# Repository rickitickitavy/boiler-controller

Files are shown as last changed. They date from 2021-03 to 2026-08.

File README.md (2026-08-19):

# Wood boiler controller

ESP32-WROOM firmware (PlatformIO / Arduino) for a wood boiler with three servo dampers (blowing, afterburning/oxygen, smoke), DS18x20 temperature sensing (boiler + thermal accumulator + house loops), and accumulated energy estimation.

## Build / flash

```bash
pio run
pio run -t upload
pio run -t uploadfs    # after changes under data/
pio device monitor     # 921600 (see platformio.ini)
```

Board: `esp32dev`. Upload port defaults to `/dev/ttyUSB0` in [`platformio.ini`](platformio.ini).

## Docs for agents / contributors

| File | Purpose |
|---|---|
| [`AGENTS.md`](AGENTS.md) | Agent entrypoint, constraints, key sources |
| [`docs/HANDOFF.md`](docs/HANDOFF.md) | Domain glossary, pins, FSM, energy math, known gaps |
| [`.cursor/skills/esp32/`](.cursor/skills/esp32/) | Project stack conventions |

## Stack snapshot

- ILI9488 TFT + XPT2046 touch
- DS18x20 on dual OneWire buses
- LEDC PWM servos for three doors
- LittleFS web UI under [`data/`](data/)
- EEPROM versioned settings (`GlobalSettings`)
- `ESPAsyncWebServer` + `AsyncTCP` via PlatformIO `lib_deps`

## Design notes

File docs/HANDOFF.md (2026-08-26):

# Wood boiler controller — handoff / context

PlatformIO project for **ESP32-WROOM** (`board = esp32dev`, `espressif32` / Arduino).  
Path: `/home/dsporynkhin/Projects/cpp/home/boilercontroller`

Use this file when starting a new chat (`@docs/HANDOFF.md`). Documented behavior is **as implemented today**.

## Domain glossary

| Domain | Code symbols |
|---|---|
| Blowing / bottom air door | `upper_door_*`, `UPPER_SERVO_PIN` |
| Afterburning / oxygen door | `oxygen_door_*`, `OXYGEN_SERVO_PIN` |
| Smoke / chimney door | `smoke_pipe_*`, `SMOKE_SERVO_PIN` |
| Fuel-loading hatch sensor | `MAIN_DOOR_SENSOR_PIN`, `main_door_opened` |
| Boiler core / out / in | `T_SENS_INDEX_CORE` / `OUTPUT_FLOW` / `INPUT_FLOW` |
| Thermal accumulator | top, middle_hi, middle_low, bottom |
| House heating supply / return | forward / backward flow |
| Stored energy | `accumulated_energy_kwt_hour` |
| Instant / smoothed core power | `current_core_power`, `core_EMA_power`, `core_DEMA_power` |
| Power balance | `power_balance_kwt_hour` (rate of change of stored energy) |

Primary goal: drive the three damper servos to burn safely (avoid overheating) and estimate accumulated thermal energy.

## Hardware (current)

Pins from [`include/pins.h`](../include/pins.h):

| Function | Macro | GPIO |
|---|---|---|
| Smoke servo | `SMOKE_SERVO_PIN` | 25 |
| Oxygen servo | `OXYGEN_SERVO_PIN` | 26 |
| Upper (blowing) servo | `UPPER_SERVO_PIN` | 27 |
| Emergency valve | `EMERGENCY_VALVE_PIN` | 0 |
| Pump 1–4 | `PUMP_1_PIN`…`PUMP_4_PIN` | 4, 13, 33, 32 |
| OneWire bus 1 / 2 | `ONE_WIRE_PIN`, `ONE_WIRE_PIN_2` | 14, **32** |
| Flow sensor | `FLOW_SENSOR_PIN` | 39 |
| TFT CS / DC / RST | `DISPLAY_*` | 17 / 15 / 16 |
| Touch CS / PENIRQ | `TOUCH_CS`, `TOUCH_PEN` | 12 / 36 |
| Fuel hatch sensor | `MAIN_DOOR_SENSOR_PIN` | 34 |
| External WDT kick | `EXTERNAL_WDT_PIN` | 5 |

- **MCU:** ESP32-WROOM (`esp32dev`)
- **Display:** custom local `lib/ILI9488` + XPT2046 touch (`TouchDisplayController`), rotation 1; Adafruit GFX / BusIO via `lib_deps`
- **Temps:** DS18x20 on two OneWire buses (`SensorController` + OneWire / DallasTemperature `lib_deps`); addresses in `GlobalSettings.ds18D20Addresses[]`
- **Doors:** three LEDC PWM servos (`Servo` / `ServoController` / `DoorsController`); all inverted; ~60 °/s rate limit
- **Pumps:** pumps 1–2 constructed in control path; 3–4 macros exist but are unused
- **FS:** **LittleFS** for web/`data/` assets (`board_build.filesystem = littlefs`)
- **Flash partitions:** stock PlatformIO **`default.csv`** — app0/app1 **1280 KB** each, LittleFS (`spiffs` subtype) **~1408 KB**, coredump **64 KB** (`board_build.partitions = default.csv`). First cutover after changing partitions needs a full erase + reflash (`upload` + `uploadfs`), not app-only OTA.
- **Web UI:** vanilla JS in `data/index.html` (Status / Settings / System shell; sidebar version `3.0.1`; Status card online time from telemetry `date_time_ms`; System inner tabs Log / Maintenance / Update) plus `data/js/*.js` — **no jQuery**. `data/settings.html` redirects to `/#settings`. TFT BMP icons remain under `data/img/`.
- **Settings:** EEPROM 4096 bytes, marker `0x34 0x32 0x33 0x31`, `GLOBAL_CURRENT_SETTINGS_VERSION` = 2

**Pin clash:** `ONE_WIRE_PIN_2` and `PUMP_4_PIN` both use GPIO **32**.

## Temperature sensors

| Index | `#define` | Settings path (approx.) | Meaning |
|---:|---|---|---|
| 0 | `T_SENS_INDEX_CORE` | `sensors>heater>core` | Boiler core |
| 1 | `T_SENS_INDEX_OUTPUT_FLOW` | `sensors>heater>output_flow` | Boiler output |
| 2 | `T_SENS_INDEX_INPUT_FLOW` | `sensors>heater>input_flow` | Boiler return/input |
| 3 | `T_SENS_INDEX_ACC_TOP` | `sensors>termoaccumulator>top` | Acc top |
| 4 | `T_SENS_INDEX_ACC_MID_HI` | `…>middle_hi` | Acc above middle |
| 5 | `T_SENS_INDEX_ACC_MID_LO` | `…>middle_low` | Acc below middle |
| 6 | `T_SENS_INDEX_ACC_BOTTOM` | `…>bottom` | Acc bottom |
| 7 | `T_SENS_INDEX_FORWARD_FLOW` | `sensors>forward>temperature` | House supply (“Warm T”) |
| 8 | `T_SENS_INDEX_BACKWARD_FLOW` | `sensors>backward>temperature` | House return |
| 9 | `T_SENS_INDEX_INTERNAL` | `sensors>internal>temperature` | Board/internal |

## Door control

### Fuel hatch override (`DoorsController::applyStatus`)

When `door_opened`: smoke **100%**, oxygen **0%** (immediate), upper **100%**. Otherwise programmed percentages apply.

### Heater modes (`HeaterMode` in `HeaterController.h`)

```
STAND_BY → WARMING → PID → FINAL_COOLING → STAND_BY
                ↘ OVERHEATED ↔ CRITICAL
Hard failsafe: core SMA ≥ 100 °C → CRITICAL
```

Comment also mentions `ALARM (BANG)` — **not implemented**.

| Mode | Smoke | Oxygen | Upper (blowing) | Notes |
|---|---|---|---|---|
| `STAND_BY` | 33% | 0% | 0% | Init-fire can temporarily open O₂ |
| `WARMING` | warming smoke % | 100% | warming upper % (gated) | Pumps typically on |
| `PID` | burning smoke % | PID `%` | burning upper % (gated) | Oxygen from `PidRegulator` |
| `FINAL_COOLING` | 33% | 0% | 0% | |
| `OVERHEATED` | 100% | 0% | 100% | Cool aggressively |
| `CRITICAL` | 100% | 0% | 100% | + emergency valve HIGH |

**Defaults:** `core_overheat` 96 °C → OVERHEATED; `core_critical` 99 °C → CRITICAL.

**Init fire** (`openOxygenDoorForTime`, default `TIME_FOR_INIT_FIRE_SEC` = 900): O₂ 100%, smoke 66%; on close → O₂ 0%, smoke 33%. UI button + web `/openDoorFor15Min`.

**Upper-door safety** (`calculateUpperDoorValue`): if power acceleration ≤ 0 **and** `core_EMA_power < core_power_to_close_upper_door_if_ICPD_W`, force upper **0%**.

**Stub:** `handle_DOOR_OPENED_mode()` is empty TODO.

## Power and accumulated energy

Constants in `Defines.h`: `WATER_ENERGY_PER_LTR_PER_GRAD` = 4200, `JOUL_PER_KWTCH` = 3_600_000, `LOWEST_TEMPERATURE_FOR_ACCUMULATOR` = 35 °C.

**Core power** (`calcMainCoreCharacteristics`):

- Pumps off: ΔT_core × `heater_core_ltr` × 4200 / Δt
- Pumps on: (T_out − T_in) × flow × 4200 / Δt  
  Then EMA / DEMA smoothing into `core_EMA_power` / `core_DEMA_power`.

**Stored energy** (`collectTelemetry`):

```
avg_acc = mean(top, bottom, mid_lo, mid_hi) SMA
E_kWh = ((T_top − 35) × boiler_ltr + (avg_acc − 35) × accumulator_ltr)
        × 4200 / 3_600_000
```

→ `accumulated_energy_kwt_hour` (UI: “Energy kWh”).

**Power balance:** `Intervals(30)` tracks stored energy over time; code then reads `getInterval(39)` while capacity is 30 — **likely buggy**; treat balance values cautiously.

## TFT UI

- Active path: `screen_index == 0` — 3×3 gauge grid + pump / init-fire / Settings buttons (`TouchDisplayController`)
- `screen_index == 1` — Settings: left vertical tabs joined to page body (Info, WiFi, Mqtt, Sensors, Servo, Capasit., Rules, Modes); idle **20 s** returns to main (unsaved drafts discarded); heater/sensors keep running while open
- **Info** tab: WiFi MAC (`esp_read_mac` STA) + WiFi Status/RSSI + MQTT Connected/Disconnected (1 s per-line refresh)
- **WiFi / MQTT / Sensors / Servo / Capasit. / Rules / Modes** tabs: scrollable forms via `SettingsTftForms` + `src/lib/ui/form/*`; on-screen keyboard `src/lib/ui/keyboard/OnScreenKeyboard.*` (may overlay footer)
- Capasit. / Rules / Modes mirror matching Web UI sections; section blocks separated by non-interactive header labels
- Number / text field limits (min/max, string max len) come from `SettingsNavigator` `ParamDescriptor`s — same ranges as web settings
- Full-width footer (**26 px**): Reload / Cancel / Save — Cancel closes without save; Save writes EEPROM **without restart**; calls `WiFiController::reapplyNetworkSettings()` **only if WiFi SSID/password changed**; always calls `MqttController::reloadFromSettings()`
- Sensors: 10 address dropdowns (discovered OneWire + `0000000000000000`); Servo order Smoke → Oxygen → Upper
- Gauges include Core T, Core P, Warm T, Output T, Pwr P, Top T, Input T, Energy kWh, Bottom T
- Mid-acc sensors feed energy math but are not dedicated main gauges
- `drawScreen1` (door % layout) largely commented out
- BMP icons from LittleFS (`/img/…`)
- Web settings UI is a tabbed page in `data/index.html` (`/settingsApi`) alongside TFT forms

## Network / OTA / persistence

| Concern | As-is behavior |
|---|---|
| WiFi | STA to `network.ssid/password`; fail → AP `{mqttDeviceName}-WiFi` / `00000000`, IP `192.168.0.1`, mDNS HTTP |
| WiFi soft reapply | `WiFiController::reapplyNetworkSettings()` — skips if already STA on configured SSID; otherwise disconnect + STA begin (or hardened AP fallback); no restart; used by TFT Save when credentials change |
| WDT | ESP task WDT disabled (`custom_sdkconfig`). External hardware WDT on `EXTERNAL_WDT_PIN` (GPIO 5) is kicked from `reset_wdt()` about every 3 s |
| Web | Async server: `/` and `/index.html` use the same `%param%` template processor as `/settings.html` (`systemSettingsProcessor`). Literal percents in SVG/JS are escaped as `%%`. Door / telemetry; modelling start/stop only when `ENABLE_MODELLING`; `POST /update/code` (alias `/update/firmware`) and `POST /update/data`; `GET /log` returns the in-memory UART log (`text/plain`)
| Display libs | Adafruit GFX + BusIO via `lib_deps`; customized driver in `lib/ILI9488/` |
| Temps libs | `paulstoffregen/OneWire` + `milesburton/DallasTemperature` via `lib_deps` |
| MQTT | `MqttController` + vendored `PubSubClient`: connect/loop/reconnect **only when WiFi mode is STA and linked to a router** (`WIFI_STA` + connected); soft-AP mode keeps MQTT idle. Uses `mqttServer`/`mqttPort`/`mqttDeviceName`; Info tab shows live status; **no publish/subscribe yet**. Failed connect uses short TCP/MQTT timeouts (~1 s) and at least **5 s** between attempts so the main loop stays responsive |
| OTA | `ArduinoOTA` in `main.cpp` with a **6 s** OTA-only window after boot and TFT progress. HTTP: `POST /update/code` or `/update/firmware` writes the unused OTA app slot (`U_FLASH`); `POST /update/data` writes the LittleFS image (`U_SPIFFS`); both reboot on success. Main loop skips heater/UI while an HTTP OTA is in progress |
| EEPROM | `SettingsManager`: versioned `GlobalSettings` + 4-byte marker |
| NTP | Implemented but call site commented out; `initNTP` uses a stack buffer (no heap alloc) |
| Heap log | `loop` logs `ESP.getFreeHeap` / `ESP.getMinFreeHeap` about once per 60 s |
| RAM console log | `Logger` keeps the same lines as UART in a **10 KB** rotating buffer (oldest complete lines dropped); web System → Log reads it via `GET /log` |
| Telemetry RAM | In-memory ring not allocated (memcpy path commented); avoids starving WiFi DMA RX buffers at boot |

## Plant modeller (compile-time)

`CoreModel` plant simulation is **off by default** (`[env:esp32dev]` has no `-DENABLE_MODELLING`). EEPROM `ModellerSettings`, web/TFT modelling parameter fields, and SettingsNavigator descriptors stay in every build.

Enable runtime simulation with `[env:esp32dev_modelling]` (`pio run -e esp32dev_modelling`). That compiles `CoreModel`, wires `/startModelling` `/stopModelling`, and shows the Settings **Advanced** tab (modelling + telemetry). Default `esp32dev` hides that tab and its label (`%modelling_hidden%` → `is-hidden`).

## Key sources

| Area | Path |
|---|---|
| Boot / OTA / loop | `src/main.cpp` |
| Heater FSM / power / energy | `src/HeaterController.*` |
| Doors / hatch override | `src/DoorsController.*` |
| Servo PWM rate limit | `src/ServoController.*`, `src/lib/servo/Servo.*` |
| DS18x20 | `src/SensorController.*` |
| TFT + gauges | `src/TouchDisplayController.*` |
| TFT Settings forms | `src/SettingsTftForms.*`, `src/lib/ui/form/*`, `src/lib/ui/keyboard/*` |
| Settings / EEPROM | `src/SettingsManager.*`, `src/GlobalSettings.h`, `src/SettingsNavigator.*` |
| WiFi / web | `src/WiFiController.*`, `src/WebServerController.*` |
| MQTT client | `src/MqttController.*`, `src/lib/mqtt/PubSubClient.*` |
| Pins | `include/pins.h` |
| Constants / log / sensor indices | `src/Defines.h` |
| UART + RAM log | `src/Logger.*` |
| Web assets | `data/` |

## Known gaps (do not “fix” unless asked)

- MQTT has connect/status only — no telemetry publish / topic subscriptions
- GPIO 32 shared by OW2 and `PUMP_4`
- `EMERGENCY_VALVE_PIN == 0` makes some `if (EMERGENCY_VALVE_PIN)` setup paths skip
- `handle_DOOR_OPENED_mode` empty; ALARM / refuel UX incomplete
- Power-balance `getInterval(39)` vs `Intervals(30)`
- Legacy `static *instance` on `HeaterController` and `TouchDisplayController` — do not expand this pattern
- `SettingsManager.cpp` includes a broken absolute ESP8266 `Esp.h` path (legacy smell)

## Working notes

- Prefer small diffs; match existing naming.
- After `data/` changes, flash filesystem (`pio run -t uploadfs`) as well as firmware.
- After changing `board_build.partitions`, erase/full-flash once so app and FS offsets match.
- Keep this handoff in sync when behavior or APIs change.

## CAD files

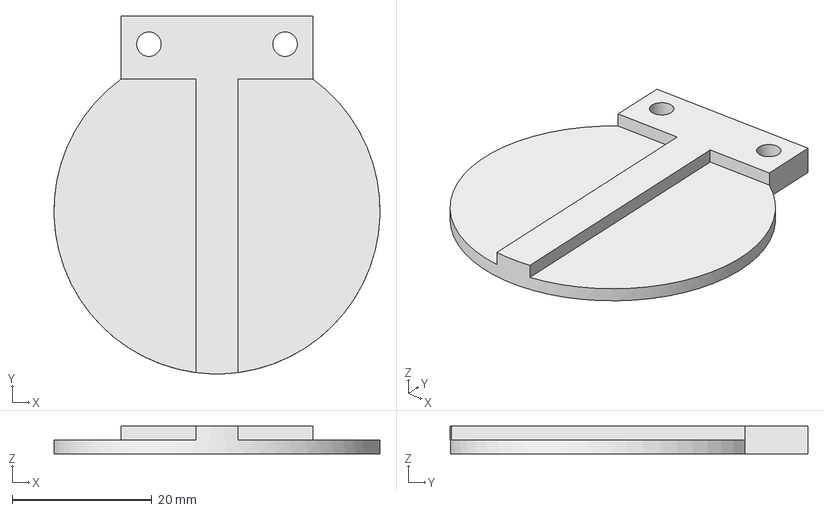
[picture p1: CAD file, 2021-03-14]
additional/boxes/freecad/Body for thin switcher.FCStd
46.6 x 51.1 x 4.00 mm

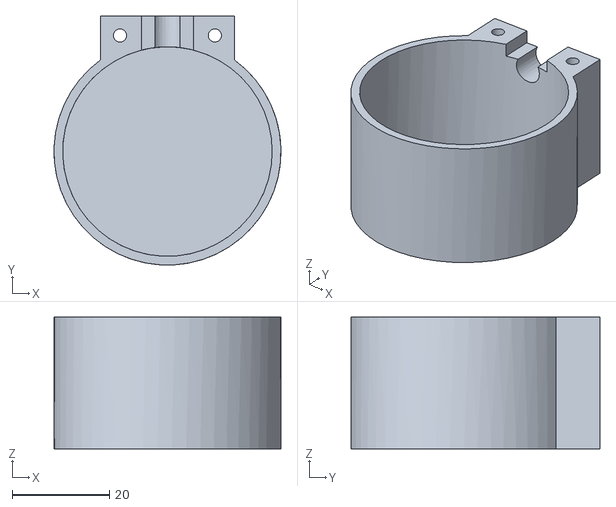
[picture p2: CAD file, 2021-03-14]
additional/boxes/stl/universalBox.stl
46.6 x 51.1 x 27.0

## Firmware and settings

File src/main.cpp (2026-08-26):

//
// Created by dsporykhin on 13.02.21.
//
#include <HardwareSerial.h>
#include <LittleFS.h>
#include "Logger.h"
#include "SettingsManager.h"
#include "ArduinoOTA.h"
#include "WiFiController.h"
#include "MqttController.h"
#include "TouchDisplayController.h"

SettingsManager *settingsManager;
WiFiController *wiFiController;
MqttController *mqttController;
SensorController *sensorController;
HeaterController *heaterController;
TouchDisplayController *touchDisplayController;
//TouchController *displayButtonController;

long lastTimeDisplayed;
long lastHeapLogMs = 0;

void twoDeviceInfo(const char *msg) {
    LOGGER.info(msg);
    touchDisplayController->printStatus(msg);

}

long last_wdt_reset = 0;

void reset_wdt() {
    // Kick external hardware WDT only (ESP task WDT is disabled).
    if (millis() - last_wdt_reset > 3000) {
        last_wdt_reset = millis();
        digitalWrite(EXTERNAL_WDT_PIN, LOW);
        delay(1);
        digitalWrite(EXTERNAL_WDT_PIN, HIGH);
    }
}

long setup_finished_at = 0;
bool screen_setup_finished = false;

void setup() {

#ifdef CON_DEBUG
    Serial.begin(921600);
    Serial.println("---");

    LOGGER.info("Started UART at 115200");
#endif
    pinMode(EXTERNAL_WDT_PIN, OUTPUT);
    reset_wdt();

    touchDisplayController = new TouchDisplayController();

    twoDeviceInfo("Starting...");
    settingsManager = new SettingsManager();

    twoDeviceInfo("starting DS18D20...");
    delay(500);
    sensorController = new SensorController(ONE_WIRE_PIN, ONE_WIRE_PIN_2, settingsManager);
    settingsManager->getNavigator()->setSensorList(sensorController->buildSensorsList());

    twoDeviceInfo("Starting heater controller...");
    heaterController = new HeaterController(settingsManager->getSettings(), sensorController,
                                            settingsManager->getNavigator());

    touchDisplayController->setHeaterController(heaterController);
    touchDisplayController->setSettingsManager(settingsManager);
    touchDisplayController->setSensorController(sensorController);

    LOGGER.info("Mounting internal flash...");
    if (!LittleFS.begin(false)) {
        LOGGER.error(" Mount Failed");
    } else
        LOGGER.info("   mounted");

    reset_wdt();
    twoDeviceInfo("starting WiFi...");
    wiFiController = new WiFiController(settingsManager);
    wiFiController->getWebServerController()->setTouchDisplayController(touchDisplayController);
    touchDisplayController->setWiFiController(wiFiController);

    twoDeviceInfo("starting MQTT...");
    mqttController = new MqttController(settingsManager);
    touchDisplayController->setMqttController(mqttController);

    twoDeviceInfo("starting HeaterController...");
    wiFiController->setHeaterController(heaterController);

    reset_wdt();
    twoDeviceInfo("starting OTA");
    ArduinoOTA.onStart([]() {
        ILI9488 *tft = touchDisplayController->getTft();
        tft->fillScreen(COLOR_BACKGROUND);
        tft->setCursor(10, 60);
        tft->print("OTA Updating...");
        LOGGER.info("OTA begins...");
    });
    ArduinoOTA.onProgress([](unsigned int progress, unsigned int total) {
        ILI9488 *tft = touchDisplayController->getTft();

        tft->fillRect(0, 120, 318, 100, COLOR_BACKGROUND);
        tft->setCursor(10, 160);
        tft->print("Loading " + String(progress) + " of " + String(total));
        LOGGER.info("OTA loading " + String(progress) + " of " + String(total));
        reset_wdt();
    });
    ArduinoOTA.onError([](ota_error_t error) {
        touchDisplayController->setScreenIndex(0);
        touchDisplayController->drawScreen();
    });
    ArduinoOTA.begin();

    twoDeviceInfo("start displayBtn controller");

    LOGGER.info("lib has " + String(settingsManager->getNavigator()->getParamDescriptorCounter()));
    delay(500);

    reset_wdt();
    twoDeviceInfo("all done");

    touchDisplayController->getTft()->fillScreen(COLOR_BACKGROUND);
    touchDisplayController->getTft()->setCursor(10, 160);
    twoDeviceInfo("WAITING FOR OTA FOR 6 SECONDS...");
    setup_finished_at = millis();
}

void loop() {
    ArduinoOTA.handle();
    wiFiController->checkConnection();
    reset_wdt();

    if (wiFiController->getWebServerController() &&
        wiFiController->getWebServerController()->isOtaInProgress()) {
        return;
    }

    // give first 6 seconds work OTA only
    if ((millis() - setup_finished_at) < 6000)
        return;
    if (!screen_setup_finished){
        twoDeviceInfo("DONE.");
        delay(500);
        touchDisplayController->setScreenIndex(0);
        lastTimeDisplayed = 0;
        LOGGER.info("display->setScreenIndex(0) done ");
        screen_setup_finished = true;
    }

    if (mqttController)
        mqttController->handle();

    touchDisplayController->handle();
    sensorController->readNextBlockOfSensors();

    if (((heaterController->handle())
#ifdef ENABLE_MODELLING
         && !heaterController->isModelling())
        || (heaterController->isModelling() && ((millis() - lastTimeDisplayed) > 3000)
#endif
        )) {


        lastTimeDisplayed = millis();
        TelemetryDataRecord *telemetryDataRecord = heaterController->getTelemetryRecord();

        touchDisplayController->setTimeToLiveValue(millis());

        touchDisplayController->updateInfo(telemetryDataRecord);
    }
    if (touchDisplayController->isDirty())
        touchDisplayController->drawScreen();

    // if ((millis() - lastHeapLogMs) >= 600000) {
    //     lastHeapLogMs = millis();
    //     char heapMsg[80];
    //     snprintf(heapMsg, sizeof(heapMsg), "heap free=%u min=%u",
    //              (unsigned) ESP.getFreeHeap(), (unsigned) ESP.getMinFreeHeap());
    //     LOGGER.info(heapMsg);
    // }

}

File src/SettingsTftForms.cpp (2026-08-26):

#include <lib/ui/fonts/BoilerFonts.h>
#include <string.h>
#include <stdio.h>
#include "SettingsTftForms.h"
#include "SettingsManager.h"
#include "SettingsNavigator.h"
#include "ParamDescriptor.h"
#include "SensorController.h"
#include "WiFiController.h"
#include "MqttController.h"
#include "Defines.h"
#include "Converter.h"
#include "HeaterSettings.h"
#include <lib/ui/form/FormColors.h>

#define UI_SETTINGS_SCREEN_WIDTH 480
#define UI_SETTINGS_SCREEN_HEIGHT 320
#define UI_SETTINGS_COLOR_PAGE 0xEF7D
#define UI_SETTINGS_COLOR_GUTTER 0xE71C
#define UI_SETTINGS_CONTENT_RADIUS 8
#define UI_SETTINGS_SECTION_HEADER_FG 0x2A79

static const int SENSOR_SETTING_INDEX[SETTINGS_SENSOR_FIELDS] = {
        T_SENS_INDEX_INTERNAL,
        T_SENS_INDEX_CORE,
        T_SENS_INDEX_OUTPUT_FLOW,
        T_SENS_INDEX_INPUT_FLOW,
        T_SENS_INDEX_ACC_TOP,
        T_SENS_INDEX_ACC_MID_HI,
        T_SENS_INDEX_ACC_MID_LO,
        T_SENS_INDEX_ACC_BOTTOM,
        T_SENS_INDEX_FORWARD_FLOW,
        T_SENS_INDEX_BACKWARD_FLOW
};

static const char *SENSOR_LABELS_FIXED[SETTINGS_SENSOR_FIELDS] = {
        "Internal", "Heater core", "Output flow", "Input flow",
        "Acc top", "Acc mid hi", "Acc mid lo", "Acc bottom",
        "Forward flow", "Backward flow"
};

struct NumberFieldSpec {
    const char *label;
    const char *param;
    bool is_float;
};

static const NumberFieldSpec CAPACITY_SPECS[SETTINGS_CAPACITY_FIELDS] = {
        {"Heater core L", "heater>capacities>heater_core_ltr", false},
        {"Accumulator L", "heater>capacities>accumulator_ltr", false},
        {"Boiler L", "heater>capacities>boiler_ltr", false},
        {"Pipes/radiators L", "heater>capacities>pipes_and_radiators_ltr", false},
};

static const NumberFieldSpec RULES_SPECS[SETTINGS_RULES_FIELDS] = {
        {"Scan interval ms", "heater>scan_interval_ms", false},
        {"Pwr to refuel W", "heater>temperature>core_pwr_to_refuel", true},
        {"Core target C", "heater>temperature>core_target", true},
        {"Core overheat C", "heater>temperature>core_overheat", true},
        {"Core critical C", "heater>temperature>core_critical", true},
        {"Acc target C", "heater>temperature>term_accumulator_target", true},
        {"SMA period sec", "heater>temperature>tempr_sma_period_sec", false},
        {"Core power EMA", "heater>temperature>core_power_ema", false},
        {"Core dP EMA", "heater>temperature>core_d_power_ema", false},
        {"Core dT EMA", "heater>temperature>core_d_tempr_ema", false},
        {"Start pumps on C", "heater>cool_pumps>start_on_tempr", true},
        {"Start dT core-in", "heater>cool_pumps>start_on_d_btw_core_inp", true},
        {"Stop dT from start", "heater>cool_pumps>stop_on_d_btw_start_core", true},
        {"ICPD interval sec", "heater>interval_for_calc_power_acc_sec", false},
        {"ICPD close pwr W", "heater>core_power_to_close_upper_door_W", false},
};

static const NumberFieldSpec MODES_SPECS[SETTINGS_MODES_FIELDS] = {
        {"Warm on power W", "heater>stanby>start_warm_on_power", true},
        {"Pwr to PID W", "heater>warming>pwr_to_sw_to_PID", true},
        {"Core T to PID C", "heater>warming>core_tempr_to_sw", true},
        {"Time to PID sec", "heater>warming>time_to_reach_pwr_sec", false},
        {"Smoke door %", "heater>warming>smoke_door_value_prc", false},
        {"Upper door %", "heater>warming>upper_door_value_prc", false},
        {"Smoke door %", "heater>pid>smoke_door_value_prc", false},
        {"Upper door %", "heater>pid>upper_door_value_prc", false},
        {"P coef", "heater>pid>p", true},
        {"I coef", "heater>pid>i", true},
        {"D coef", "heater>pid>d", true},
        {"Max I", "heater>pid>max_i", true},
        {"Min I", "heater>pid>min_i", true},
        {"Pwr to warm W", "heater>pid>pwr_to_sw_to_warm", true},
        {"Oxy door to warm", "heater>pid>oxy_door_to_sw_warm", true},
        {"T to standby C", "heater>final_cool>tempr_to_sw_to_stby", true},
        {"Pwr to warm W", "heater>final_cool>start_on_d_btw_core_inp", true},
        {"Delay to standby s", "heater>final_cool>delay_to_sw_to_stnby", false},
};

// Slot layout: header indices then field indices interleaved by section.
// Capacities: H0, F0..F3
// Rules: H0, F0..F9, H1, F10..F12, H2, F13..F14
// Modes: H0, F0, H1, F1..F5, H2, F6..F14, H3, F15..F17

static int capacitySlotForField(int field_i) { return 1 + field_i; }

static int rulesSlotForField(int field_i) {
    if (field_i < 10) return 1 + field_i;
    if (field_i < 13) return 12 + (field_i - 10);
    return 16 + (field_i - 13);
}

static int modesSlotForField(int field_i) {
    if (field_i < 1) return 1 + field_i;
    if (field_i < 6) return 3 + (field_i - 1);
    if (field_i < 15) return 9 + (field_i - 6);
    return 19 + (field_i - 15);
}

static int rulesHeaderSlot(int header_i) {
    if (header_i == 0) return 0;
    if (header_i == 1) return 11;
    return 15;
}
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

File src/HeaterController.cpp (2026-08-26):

//
// Created by dsporykhin on 25.03.22.
//

#include <lib/math/Intervals.h>
#include "HeaterController.h"
#include "Defines.h"

HeaterController *HeaterController::instance = nullptr;

HeaterController::HeaterController(GlobalSettings *settings, SensorController *sensorController,
                                   SettingsNavigator *settingsNavigator) {
    this->settings = settings;
    this->heaterSettings = &settings->heaterSettings;
    this->sensorController = sensorController;
    this->settingsNavigator = settingsNavigator;
    instance = this;
#ifdef ENABLE_MODELLING
    modelling_is_active = false;
#endif
    flowSensor = new FlowSensor(FLOW_SENSOR_PIN);

    power_balance = new Intervals(30);

    if (EMERGENCY_VALVE_PIN) {
        pinMode(EMERGENCY_VALVE_PIN, OUTPUT);
        digitalWrite(EMERGENCY_VALVE_PIN, LOW);
    }

    cycle_index = 0;

    doorsController = new DoorsController(&heaterSettings->servos_hardware_settings);

    pidRegulator = new PidRegulator(heaterSettings, sensorController, &mainCoreParams);

    last_cycle_time = 0;

    pumpsController = new PumpsController(heaterSettings);

    telemetry = new Telemetry(settings);

    previous_core_temperature = 0;
    mainCoreParams.core_DEMA_temperature = 0;

    resetDEMAtimers();

    two_pump_active_delta_core_input = false;
    two_pump_active_delta_core_output = false;

    flow_ticks = 0;

#ifdef ENABLE_MODELLING
    coreModel = new CoreModel(&settings->heaterSettings, pumpsController, doorsController, telemetry);
#endif

    time_to_close_oxygen_door_in_stanby_mode = 0;

    cycle_index = 10000;
#ifdef ENABLE_MODELLING
    estimated_modelling_cycle_counter = 0;

    settingsNavigator->addParamDescriptor(new ParamDescriptor("heater>modelling>est_modelling_cycles", INTEGER,
                                                              100,
                                                              50000,
                                                              (void *) &estimated_modelling_cycle_counter,
                                                              (void *) nullptr));

    settingsNavigator->addParamDescriptor(new ParamDescriptor("heater>modelling>current_stage", INTEGER,
                                                              100,
                                                              50000,
                                                              (void *) &coreModel->stage_index,
                                                              (void *) nullptr));
#else
    static int estimated_modelling_cycle_counter = 0;
    static int modelling_current_stage = 0;
    settingsNavigator->addParamDescriptor(new ParamDescriptor("heater>modelling>est_modelling_cycles", INTEGER,
                                                              100,
                                                              50000,
                                                              (void *) &estimated_modelling_cycle_counter,
                                                              (void *) nullptr));

    settingsNavigator->addParamDescriptor(new ParamDescriptor("heater>modelling>current_stage", INTEGER,
                                                              100,
                                                              50000,
                                                              (void *) &modelling_current_stage,
                                                              (void *) nullptr));
#endif

    // init history buffer for the average power acceleration
    core_power_history_size = settings->interval_for_calc_power_different_sec * 1000 / settings->heaterSettings.scan_interval_ms + 1;
    core_power_history = (float *) malloc(sizeof (float) * core_power_history_size);
    memset(core_power_history, 0, core_power_history_size * sizeof (float));

    pinMode(MAIN_DOOR_SENSOR_PIN, INPUT_PULLUP);
    attachInterrupt(MAIN_DOOR_SENSOR_PIN, MAIN_DOOR_ISR, CHANGE);
    MAIN_DOOR_ISR();
    previous_main_door_opened = false;
}

void HeaterController::resetDEMAtimers() {
    mainCoreParams.DiffEMA_rose_above_zero_at = 0;
    mainCoreParams.DiffEMA_down_bellow_zero_at = 0;
}

void IRAM_ATTR HeaterController::MAIN_DOOR_ISR() {
    bool door_mode = digitalRead(MAIN_DOOR_SENSOR_PIN);
    instance->main_door_opened = door_mode;
}

void HeaterController::collectTelemetry(long last_cycle_length) {
    telemetryDataRecord.interval_ms = last_cycle_length;
    telemetryDataRecord.date_time_ms = millis();
    telemetryDataRecord.core_temp = (float) sensorController->sensor_data[T_SENS_INDEX_CORE].value;
    telemetryDataRecord.output_temp = (float) sensorController->sensor_data[T_SENS_INDEX_OUTPUT_FLOW].value;
    telemetryDataRecord.input_temp = (float) sensorController->sensor_data[T_SENS_INDEX_INPUT_FLOW].value;
    telemetryDataRecord.accumulator_higher_temp = (float) sensorController->sensor_data[T_SENS_INDEX_ACC_MID_HI].value;
    telemetryDataRecord.accumulator_lower_temp = (float) sensorController->sensor_data[T_SENS_INDEX_ACC_MID_LO].value;
    telemetryDataRecord.accumulator_bottom_temp = (float) sensorController->sensor_data[T_SENS_INDEX_ACC_BOTTOM].value;
    telemetryDataRecord.accumulator_top_temp = (float) sensorController->sensor_data[T_SENS_INDEX_ACC_TOP].value;
    telemetryDataRecord.forwar_flow_temp = (float) sensorController->sensor_data[T_SENS_INDEX_FORWARD_FLOW].value;
    telemetryDataRecord.backward_flow_temp = (float) sensorController->sensor_data[T_SENS_INDEX_BACKWARD_FLOW].value;

    telemetryDataRecord.internal_temp = sensorController->getNotNANValue(T_SENS_INDEX_INTERNAL);
    telemetryDataRecord.core_temp_sma = sensorController->getNotNANSmaValue(T_SENS_INDEX_CORE);
    telemetryDataRecord.output_temp_sma = sensorController->getNotNANSmaValue(T_SENS_INDEX_OUTPUT_FLOW);
    telemetryDataRecord.input_temp_sma = sensorController->getNotNANSmaValue(T_SENS_INDEX_INPUT_FLOW);
    telemetryDataRecord.accumulator_higher_temp_sma = sensorController->getNotNANSmaValue(
            T_SENS_INDEX_ACC_MID_HI);
    telemetryDataRecord.accumulator_lower_temp_sma = sensorController->getNotNANSmaValue(
            T_SENS_INDEX_ACC_MID_LO);
    telemetryDataRecord.accumulator_bottom_temp_sma = sensorController->getNotNANSmaValue(
            T_SENS_INDEX_ACC_BOTTOM);
    telemetryDataRecord.accumulator_top_temp_sma = sensorController->getNotNANSmaValue(T_SENS_INDEX_ACC_TOP);
    telemetryDataRecord.forwar_flow_temp_sma = sensorController->getNotNANSmaValue(T_SENS_INDEX_FORWARD_FLOW);
    telemetryDataRecord.backward_flow_temp_sma = sensorController->getNotNANSmaValue(
            T_SENS_INDEX_BACKWARD_FLOW);
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

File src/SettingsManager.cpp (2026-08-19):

#include "SettingsNavigator.h"//
#include "Logger.h"
#include "Converter.h"
#include "../../../../../.platformio/packages/framework-arduinoespressif8266/cores/esp8266/Esp.h"
// Created by dsporykhin on 23.04.20.
//

#include <EEPROM.h>
#include <FS.h>
#include <LittleFS.h>
#include <string.h>

// Force a terminator and cut at the first non-printable byte.
// Fixes legacy mqttServer init that memcpy'd "192.168.4.254" without '\0',
// so strlen ran into trailing garbage and backspace seemed broken.
static void sanitizeCString(char *buf, size_t buf_size) {
    if (!buf || buf_size == 0)
        return;
    buf[buf_size - 1] = 0;
    for (size_t i = 0; i < buf_size - 1; i++) {
        unsigned char c = (unsigned char) buf[i];
        if (c == 0)
            return;
        if (c < 32 || c > 126) {
            buf[i] = 0;
            return;
        }
    }
}

SettingsManager::SettingsManager(){

    EEPROM.begin(4096);
    LOGGER.info("Load settings...");
    readSettings();
    sanitizeCString(settings.network.ssid, sizeof(settings.network.ssid));
    sanitizeCString(settings.network.password, sizeof(settings.network.password));
    sanitizeCString(settings.mqttServer, sizeof(settings.mqttServer));
    sanitizeCString(settings.mqttDeviceName, sizeof(settings.mqttDeviceName));
    sanitizeCString(settings.deviceStateOutgoingTopicPrefix, sizeof(settings.deviceStateOutgoingTopicPrefix));
    sanitizeCString(settings.deviceIHaveBornTopic, sizeof(settings.deviceIHaveBornTopic));
    sanitizeCString(settings.deviceIncomingCommandTopicPrefix, sizeof(settings.deviceIncomingCommandTopicPrefix));
    sanitizeCString(settings.mqttServerBornTopic, sizeof(settings.mqttServerBornTopic));
    sanitizeCString(settings.mqttInputToolTopic, sizeof(settings.mqttInputToolTopic));
    sanitizeCString(settings.mqttOutputToolTopic, sizeof(settings.mqttOutputToolTopic));

    LOGGER.info("------------------ read ------------- ");
    LOGGER.info("      scan_interval_ms: " + String(settings.heaterSettings.scan_interval_ms));
    LOGGER.info("      SMA_temperature_period_sec: " + String(settings.heaterSettings.temperatureSettings.SMA_temperature_period_sec));

    navigator = new SettingsNavigator(this);

    if ((settings.initMarker[0] != GLOBAL_SETTINGS_MARKER_0)
        || (settings.initMarker[1] != GLOBAL_SETTINGS_MARKER_1)
        || (settings.initMarker[2] != GLOBAL_SETTINGS_MARKER_2)
        || (settings.initMarker[3] != GLOBAL_SETTINGS_MARKER_3)) {
        // настройки не инициализированы

        settings.initMarker[0] = GLOBAL_SETTINGS_MARKER_0;
        settings.initMarker[1] = GLOBAL_SETTINGS_MARKER_1;
        settings.initMarker[2] = GLOBAL_SETTINGS_MARKER_2;
        settings.initMarker[3] = GLOBAL_SETTINGS_MARKER_3;

        LOGGER.error("Settings has never been initialized. Initializing by default config...");

        settings.version = GLOBAL_CURRENT_SETTINGS_VERSION;

        // Заполнение дефолтными значениями
        resetWiFi();

        settings.mqttPort = 1883;
        memset(settings.mqttServer, 0, sizeof(settings.mqttServer));
        strncpy(settings.mqttServer, "192.168.4.254", sizeof(settings.mqttServer) - 1);
        settings.mqttReconnectIntervalMs = 1000;

        memset(settings.mqttDeviceName, 0, sizeof(settings.mqttDeviceName));
        strncpy(settings.mqttDeviceName, "heater-test", sizeof(settings.mqttDeviceName) - 1);

        memcpy(settings.deviceStateOutgoingTopicPrefix, String("state").c_str(), 5);
        settings.deviceStateOutgoingTopicPrefix[5] = 0;

        memcpy(settings.deviceIncomingCommandTopicPrefix, String("command").c_str(), 8);
        settings.deviceIncomingCommandTopicPrefix[7] = 0;

        memcpy(settings.deviceIHaveBornTopic, String("deviceReady").c_str(), 11);
        settings.deviceIHaveBornTopic[11] = 0;

        memcpy(settings.mqttServerBornTopic, String("homeassistant/status").c_str(), 20);
        settings.mqttServerBornTopic[20] = 0;

        memset(&settings.mqttInputToolTopic, 0, 32);
        memset(&settings.mqttOutputToolTopic, 0, 32);

        settings.defaultSwitcherState = false;
        settings.dimmerPwmValue = 50;

        memset(settings.ds18D20Addresses, 0, sizeof(settings.ds18D20Addresses));

        initServoConfig(&settings.heaterSettings.servos_hardware_settings.oxygen_servo_settings);
        initServoConfig(&settings.heaterSettings.servos_hardware_settings.smoke_servo_settings);
        initServoConfig(&settings.heaterSettings.servos_hardware_settings.upper_door_servo_settings);
        settings.heaterSettings.servos_hardware_settings.oxygen_servo_settings.working_max_angle = 180;

        settings.heaterSettings.capacities_setting.boiler_ltr = 200;
        settings.heaterSettings.capacities_setting.heater_core_ltr = 100;
        settings.heaterSettings.capacities_setting.accumulator_ltr = 1000;
        settings.heaterSettings.capacities_setting.pipes_and_radiators_ltr = 100;

        settings.heaterSettings.scan_interval_ms = 3000;
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

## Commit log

2021-02-20 switcher.
    fail mqtt
2021-02-20 switcher works fine
2021-03-14 small unneeded fix for net and levels
    [main.cpp]
2021-03-14 schemes, boxes
    [Body for thin switcher.FCStd, main.schdoc, universalBox.stl]
2021-05-07 define switcher pin
2022-02-26 DS18D20 many sensors
2022-03-08 sensor controller. Configuring sensor channels
2022-03-12 configure sensors
2022-03-12 configure 3 more sensors
2022-03-25 added PWM controller added servo driver added settings for PWM and servos added BOOLEAN parameters and support write UCHAR
2022-03-28 ESP32 review
2022-04-03 heater settings new design for settings
2022-04-17 settings for heater settings added to navigator partially added to settings page
2022-04-18 added temperature settings
2022-04-25 1) PID 2) Controller
2022-05-02 fix DS18D20 driver
2022-05-24 modes pumps and more
2022-05-24 stop pumps
2022-06-05 added power of core. Added flow sensor pre-support
2022-06-17 not fails if it will be uploaded
    [Defines.h, DoorsController.cpp, HeaterController.cpp]
2022-07-17 fix Servo + settings
    [ServoController.cpp, SettingsManager.cpp, main.cpp]
2022-07-18 FLOW sensor, read values on settings page
2022-07-22 added main door sensor, UI and refactoring
2022-08-03 display button, internal termo, fix sensors setup
    [Defines.h, Display.cpp, HeaterController.cpp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]
2022-10-01 many fixes maiden after tests on real heater veissmann
    [Display.cpp, DoorsController.cpp, HeaterController.cpp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]
2022-10-11 smoothed movement of servos
2022-10-19 acc power balance (draft)
2022-10-23 acc power balance fix
    [Defines.h, main.cpp]
2023-01-12 support hardware watchdog timer
2023-01-15 TODO fix flow error
    [Defines.h, Display.cpp, HeaterController.cpp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]
2023-01-16 flow error fixed
2023-01-18 refactoring, added object button
2023-01-18 buttons for pumps and init fire. As button not active
2023-02-26 added support for 2 1-wire interfaces
2024-03-11 Live timer
2024-03-11 1) new indicator for a sensor fail 2) smart upper door control (betta) 3) settings version patch
    [HeaterController.cpp, Logger.cpp, SettingsManager.cpp]
2026-08-17 fixes, asyncWebSerer as lib
    [PumpController.cpp, SettingsManager.cpp, Telemetry.cpp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]
2026-08-17 compacting the data segment, enlarging the code segment. Some fixes
    [main.cpp]
2026-08-20 The Web UI redesign
    [SettingsNavigator.cpp, WebServerController.h, main.cpp]
2026-08-20 1)TFT UI added doors and PID info
    2) Added Reboot button on the Web UI
    [TouchDisplayController.cpp, TouchDisplayController.h, WebServerController.h]
2026-08-24 resize the partitions
    [partitions_4mb_ota_512fs.csv]
2026-08-26 reduce code segment
    [partitions_4mb_ota_512fs.csv]
2026-10-19 Publish accumulate/spend power as float with two decimals in MQTT STATE.
    Keep INT_MAX-scale garbage sanitized to 0; bump firmware to 3.0.6 and align the mqtt-client spec.
